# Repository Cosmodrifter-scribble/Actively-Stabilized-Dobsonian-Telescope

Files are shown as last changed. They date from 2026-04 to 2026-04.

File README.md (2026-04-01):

# Actively Stabilized Dobsonian Telescope

> An 8" f/5 GPS-controlled motorized Dobsonian telescope built completely from scratch — with closed-loop tracking, active stabilization, and Stellarium control. Built by Vinayak Soni, Indore, India.

---

## What is this?

This is a fully custom-built 8" Newtonian reflecting telescope on a motorized Dobsonian alt-azimuth mount. It started as a simple tracking telescope and evolved into something significantly more capable — a GPS-aligned, actively stabilized, astrophotography-ready instrument built for under ₹55,000 (~$580 USD).

A Celestron NexStar 8" costs over $2,000, lacks most of these features, and you'd never understand how it works. This one I built myself, and I understand every single part of it.

---

## Why I built this

I wanted to understand how modern telescopes actually work — not just use one. That meant building one from scratch, designing every subsystem, and solving every problem myself. Along the way the project grew from "make a basic tracker" into a full closed-loop stabilized GoTo system. The constraint of being in India — where quality optics are hard to find and Aliexpress is banned — pushed me to be creative and resourceful in ways I wouldn't have been otherwise.

---

## How to use it

1. Power on via the main switch — ESP32 boots, TMC2209 drivers initialize
2. Wait 30–60 seconds for NEO-M8N GPS to acquire satellite lock (blue LED turns on)
3. Select a target using the D-pad + OLED menu, or connect Stellarium on your phone over WiFi and click any object
4. Telescope slews to target automatically — both AZ and ALT axes move simultaneously
5. Sidereal tracking begins automatically — object stays centered as Earth rotates
6. Active stabilization via MPU9250 IMU corrects for vibration and wind at 200Hz
7. For astrophotography — attach DSLR via T-ring to the 2" Crayford focuser

---

## Features

| Feature | Details |
|---|---|
| GPS alignment | NEO-M8N — location + time on boot, no manual star alignment |
| Active stabilization | MPU9250 IMU at 200Hz — corrects vibration, wind shake, bumps |
| Closed-loop tracking | 1000PPR optical encoders on both axes — catches missed steps |
| Silent motors | TMC2209 at 32× microstepping — zero vibration |
| GoTo | Stellarium over WiFi (LX200 protocol) + built-in object catalogue |
| AZ accuracy | 360T ring gear — 0.003° per step |
| ALT accuracy | 120T GT2 belt — 0.009° per step |
| Dual core | ESP32-S3 — tracking on Core 0, UI/WiFi on Core 1 |

---

## Specifications

### Optics

| Parameter | Value |
|---|---|
| Primary mirror | GSO 8" f/5 parabolic, 203mm aperture, 1000mm focal length |
| Secondary mirror | GSO 50mm elliptical flat, 1/12 wave |
| Focuser | 2" Crayford (Marcos ATM design, modified for 228.6mm tube) |
| Limiting magnitude | ~14.5 |
| Magnification range | 31× to 250× |

### Tube

| Parameter | Value |
|---|---|
| Tube material | Aluminium |
| Tube OD | 228.6mm |
| Tube ID | 218.6mm |
| Total length | 1100mm |
| Spider position from top | 110mm |
| Secondary position from top | 154mm |
| Primary mirror position from top | 1000mm |
| Secondary offset | 2.26mm toward primary |

### Mount

| Parameter | Value |
|---|---|
| Mount type | Dobsonian alt-azimuth rocker box |
| Rocker box material | 12mm plywood (laser cut) |
| Side panels | 350×680mm |
| AZ bearing | 12" lazy susan + Teflon pads |
| ALT bearing | 25mm aluminium pipe + 2× 6205-2RS bearings |

### Drive System

| Axis | System | Ratio | Steps/rev | Accuracy |
|---|---|---|---|---|
| AZ | 360T Module 1 spur gear ring + 20T pinion | 18:1 | 115,200 | 0.003°/step |
| ALT | 120T GT2 belt + 20T pinion | 6:1 | 38,400 | 0.009°/step |

### Electronics

| Component | Spec |
|---|---|
| Controller | ESP32-S3-DevKitC-1-N8R8 |
| Motor drivers | 2× TMC2209 SilentStepStick, 32× microstep |
| Motors | 2× NEMA17, 4.2kg-cm, 1.8°/step |
| GPS | NEO-M8N with ceramic active antenna |
| IMU | MPU9250 9-axis (I2C 0x68) |
| Encoders | 2× 1000PPR AB-phase NPN open collector |
| Display | 1.3" 128×64 OLED (I2C 0x3C) |
| Power | 12V DC adapter → LM2596 buck → 5V → ESP32 |
| PCB | Custom 2-layer, 150×100mm |

---

## GPIO Assignment

| GPIO | Function |
|---|---|
| GPIO1 | AZ STEP |
| GPIO2 | AZ DIR |
| GPIO3 | ALT STEP |
| GPIO4 | ALT DIR |
| GPIO5 | TMC AZ UART (PDN) |
| GPIO6 | TMC ALT UART (PDN) |
| GPIO7 | TMC EN (both, active LOW) |
| GPIO8 | GPS TX |
| GPIO9 | GPS RX |
| GPIO10 | I2C SDA (IMU + Display) |
| GPIO11 | I2C SCL (IMU + Display) |
| GPIO12 | ALT Encoder A |
| GPIO13 | ALT Encoder B |
| GPIO14 | AZ Encoder A |
| GPIO15 | AZ Encoder B |
| GPIO19 | D-PAD CENTER |
| GPIO20 | D-PAD UP |
| GPIO21 | D-PAD DOWN |
| GPIO35 | D-PAD LEFT |
| GPIO36 | D-PAD RIGHT |
| GPIO37 | Toggle switch |
| GPIO38 | LED PWR (green) |
| GPIO39 | LED GPS (blue) |
| GPIO40 | LED TRACK (yellow) |
| GPIO41 | Battery ADC (12V → 3V via 27K+10K divider) |

---

## Repository Structure

```
Actively-Stabilized-Dobsonian-Telescope/
│
├── README.md
├── BOM.csv                          ← Full bill of materials with links
│
├── PCB/
│   ├── nigga.kicad_pro              ← KiCad project file
│   ├── nigga.kicad_sch              ← Schematic
│   ├── nigga.kicad_pcb              ← PCB layout
│   ├── gerbers/                     ← Gerber + drill files (zip for JLCPCB)
│   │   └── pcb_com.zip
│   ├── pcb_com_bom.csv              ← PCB BOM from KiCad
│   ├── pcb_com_positions.csv        ← Component placement file
│   ├── pcb_com_designators.csv      ← Designator reference
│   └── netlist.ipc                  ← IPC netlist
│
├── CAD/
│   ├── telescope.step               ← Full 3D assembly (STEP)
│   └── onshape_link.txt             ← Link to OnShape public document
│
├── firmware/
│   └── (in progress)
│
└── docs/
    └── (wiring diagrams, references)
```

---

## Build Progress

- [x] Mirror selection and optics sourcing
- [x] Mechanical design (OnShape)
- [x] Drive system design (AZ ring gear + ALT belt)
- [x] Schematic design (KiCad)
- [x] PCB layout and fabrication files
- [x] 3D printed parts design
- [ ] Firmware (in progress)
- [ ] Physical assembly
- [ ] Testing and calibration

---

## 3D Printed Parts

All parts printed in PETG. Source files in OnShape (link in `CAD/onshape_link.txt`).

| Part | Infill | Layer height |
|---|---|---|
| AZ ring gear segments (×6) | 60% | 0.15mm |
| ALT GT2 pulley 120T | 60% | 0.15mm |
| AZ pinion 20T | 80% | 0.15mm |
| ALT pinion 20T | 80% | 0.15mm |
| Mirror cell | 40% | 0.2mm |
| Spider hub | 40% | 0.2mm |
| Secondary mirror holder | 40% | 0.2mm |
| Motor mounts (×2) | 40% | 0.2mm |
| Tube rings (×2) | 20% | 0.2mm |
| Focuser mounting plate | 40% | 0.2mm |

---

## PCB

Custom 2-layer PCB designed in KiCad. All major modules (ESP32, GPS, IMU, motor drivers) are socketed for easy replacement and upgrades.

**Key design decisions:**
- TMC2209 modules in sockets — swappable without desoldering
- ESP32-S3 DevKit in pin headers — removable for programming
- LM2596 buck converter module for 12V→5V
- Separate power rails for motors (12V) and logic (3.3V)
- Ground planes on both F.Cu and B.Cu layers
- 1.5mm traces for power, 0.5mm for signals

Gerber files ready for JLCPCB or PCBWay in `PCB/gerbers/pcb_com.zip`.

---

## Acknowledgements

- **Marcos ATM** — 2" Crayford focuser design: https://marcosatm.com/2020/06/04/2in-crayford-focuser/
- **Thingiverse** — Focuser STL files: https://www.thingiverse.com/thing:4424419
- **Tejraj & Co.** — GSO optics supplier, India: +91 98339 74700

---

## Some Pic 

Screenshot (112)
Screenshot (111)
Screenshot (110)
Screenshot (109)
Screenshot (108)
Screenshot (107)
Screenshot (106)
Screenshot (105)
Screenshot (104)
Screenshot (103)
Screenshot (102)
Screenshot (101)
Screenshot (100)
Screenshot (99)

---

## Bill of Materials

| # | Component | Qty | Unit (₹) | Total (₹) | Source |
|---|---|---|---|---|---|
| 1 | [GSO 8" f/5 primary mirror](https://www.tejraj.com/product/gso-8-f5-parabolic-mirror) | 1 | ₹13,000 | ₹13,000 | Tejraj & Co. |
| 2 | [GSO 50mm secondary mirror](https://www.tejraj.com/product/50mm-secondary-mirror) | 1 | ₹5,500 | ₹5,500 | Tejraj & Co. |
| 3 | [32mm Plossl eyepiece](https://www.tejraj.com/product/32mm-plossl-eyepiece-125) | 1 | ₹3,350 | ₹3,350 | Tejraj & Co. |
| 4 | GSO 2" Crayford focuser + hardware | 1 | TBD | TBD | Local / Tejraj |
| 5 | [ESP32-S3-DevKitC-1-N8R8](https://www.electropi.in/espressif-esp32-s3-devkitc-1-n8r8-development-board) | 1 | ₹1,500 | ₹1,500 | Electropi.in |
| 6 | [NEMA17 4.2kg-cm stepper motor](https://robu.in/product/nema17-4-2-kgcm-stepper-motor/) | 2 | ₹700 | ₹1,400 | Robu.in |
| 7 | [TMC2209 stepper driver module](https://www.electropi.in/tmc2209-stepper-motor-driver-module) | 2 | ₹400 | ₹800 | Electropi.in |
| 8 | [1000PPR optical encoder (AB phase NPN)](https://www.amazon.in/Techtonics-2-Phase-Incremental-Optical-Quadrature/dp/B0DCK8HMHN) | 2 | ₹1,850 | ₹3,700 | Amazon.in |
| 9 | [LM2596 buck converter module](https://robu.in/product/lm2596s-dc-dc-buck-converter-power-supply/) | 1 | ₹45 | ₹45 | Robu.in |
| 10 | [MPU9250 9-axis IMU](https://www.electropi.in/mpu9250-9-axis-gyro-accelerometer-module) | 1 | ₹350 | ₹350 | Electropi.in |
| 11 | [NEO-M8N GPS module](https://www.electropi.in/neo-m8n-gps-module-with-ceramic-active-antenna) | 1 | ₹900 | ₹900 | Electropi.in |
| 12 | [1.3" 128×64 OLED display](https://www.electropi.in/1.3-inch-128x64-oled-display-screen-module-with-spi-serial-interface-v2) | 1 | ₹350 | ₹350 | Electropi.in |
| 13 | Custom PCB (2-layer, 150×100mm) | 1 | ₹2,500 | ₹2,500 | JLCPCB / PCBWay |
| 14 | Resistor 4.7K (encoder pullup) | 4 | TBD | TBD | Local Palasia |
| 15 | Resistor 330Ω (LED) | 3 | TBD | TBD | Local Palasia |
| 16 | Resistor 10K (EN pullup + I2C) | 3 | TBD | TBD | Local Palasia |
| 17 | Resistor 27K (ADC divider) | 1 | TBD | TBD | Local Palasia |
| 18 | Capacitor 100µF electrolytic | 2 | TBD | TBD | Local Palasia |
| 19 | LED green + blue + yellow 5mm | 3 | TBD | TBD | Local Palasia |
| 20 | JST 4-pin connector (motor ×2, display ×1, GPS ×1) | 4 | TBD | TBD | Local Palasia |
| 21 | JST 5-pin connector (encoder) | 2 | TBD | TBD | Local Palasia |
| 22 | JST 10-pin connector (IMU) | 1 | TBD | TBD | Local Palasia |
| 23 | Toggle switch SPDT | 2 | TBD | TBD | Local Palasia |
| 24 | 5-way tactile switch breakout 7-pin | 1 | TBD | TBD | Robu.in / Amazon |
| 25 | Pin headers male/female | — | TBD | TBD | Local Palasia |
| 26 | 12V DC adapter 3A | 1 | TBD | TBD | Local / Amazon |
| 27 | Wiring (various) | — | TBD | TBD | Local Palasia |
| 28 | Aluminium tube (telescope body) | 1 | TBD | TBD | Local Indore |
| 29 | 12mm plywood (rocker box + ground board) | 1 | ₹1,000 | ₹1,000 | Local Indore |
| 30 | Plywood laser cutting | 1 | ₹1,000 | ₹1,000 | Local Indore |
| 31 | [12" lazy susan bearing](https://www.amazon.in/BOSCO-Swivel-Turntable-Rotating-Furniture/dp/B0GSGZFKGD) | 1 | ₹650 | ₹650 | Amazon.in |
| 32 | Spider vane steel strip 0.8×15×109mm | 4 | TBD | TBD | Local Palasia |
| 33 | 25mm aluminium pipe (ALT axis) | 1 | TBD | TBD | Local Indore |
| 34 | 6205-2RS bearing 25mm bore | 2 | TBD | TBD | Local Indore |
| 35 | GT2 belt 6mm | 1 | TBD | TBD | Robu.in |
| 36 | Teflon pads | 3 | TBD | TBD | Local hardware |
| 37 | M3 screws (secondary ×3, tube ×4, pulleys ×4) | 11 | TBD | TBD | Local Palasia |
| 38 | M4 screws (big pulley ×2) | 2 | TBD | TBD | Local Palasia |
| 39 | M5 screws (primary cell ×6) | 6 | TBD | TBD | Local Palasia |
| 40 | M6 screws (tube rings ×6) | 6 | TBD | TBD | Local Palasia |
| 41 | Nylon M2 screws (mirror holder) | 6 | TBD | TBD | Local Palasia |
| 42 | All PETG 3D printed parts | 1 | ₹10,000 | ₹10,000 | 3Ding.in / Aprintpro |
| 43 | RTV silicone (mirror mounting) | 1 | TBD | TBD | Local hardware |
| — | **Total (known)** | | | **₹46,045** | **≈ $490 USD** |

---

*Built in Indore, Madhya Pradesh, India.*

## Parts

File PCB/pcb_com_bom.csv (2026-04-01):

Designator | Footprint | Quantity | Value | LCSC Part #
C1, C2 | CP_Radial_D6.3mm_P2.50mm | 2 | 100µF
D1, D2, D3 | LED_D5.0mm | 3 | LED
J1 | BarrelJack_CUI_PJ-102AH_Horizontal | 1 | JACK
J10 | PinHeader_1x04_P2.54mm_Vertical | 1 | M_ALT
J11 | PinHeader_1x04_P2.54mm_Vertical | 1 | M_AZ
J2 | PinHeader_1x03_P2.54mm_Vertical | 1 | MAIN SWITCH
J3 | PinHeader_1x05_P2.54mm_Vertical | 1 | EN_ALT
J4 | PinHeader_1x05_P2.54mm_Vertical | 1 | EN_AZ
J5 | PinHeader_1x04_P2.54mm_Vertical | 1 | GPS
J6 | PinHeader_1x10_P2.54mm_Vertical | 1 | IMU
J7 | PinHeader_1x04_P2.54mm_Vertical | 1 | DISPLAY
J8 | PinHeader_1x03_P2.54mm_Vertical | 1 | SWITCH
J9 | PinHeader_1x07_P2.54mm_Vertical | 1 | D-PAD
PS1 | CONV_MC00100 | 1 | LM2596
R1, R12 | R_Axial_DIN0207_L6.3mm_D2.5mm_P10.16mm_Horizontal | 2 | 10K
R10, R2, R3, R4, R5, R9 | R_Axial_DIN0207_L6.3mm_D2.5mm_P10.16mm_Horizontal | 6 | 4.7K
R11 | R_Axial_DIN0207_L6.3mm_D2.5mm_P10.16mm_Horizontal | 1 | 27K
R6, R7, R8 | R_Axial_DIN0207_L6.3mm_D2.5mm_P10.16mm_Horizontal | 3 | 330
U1 | MODULE_TMC2209_SILENTSTEPSTICK | 1 | ALT
U2 | MODULE_TMC2209_SILENTSTEPSTICK | 1 | AZ
U3 | ESP32-S3-DEVKITC-1-N8R8 | 1 | ESP32-S3-DEVKITC-1-N8R8

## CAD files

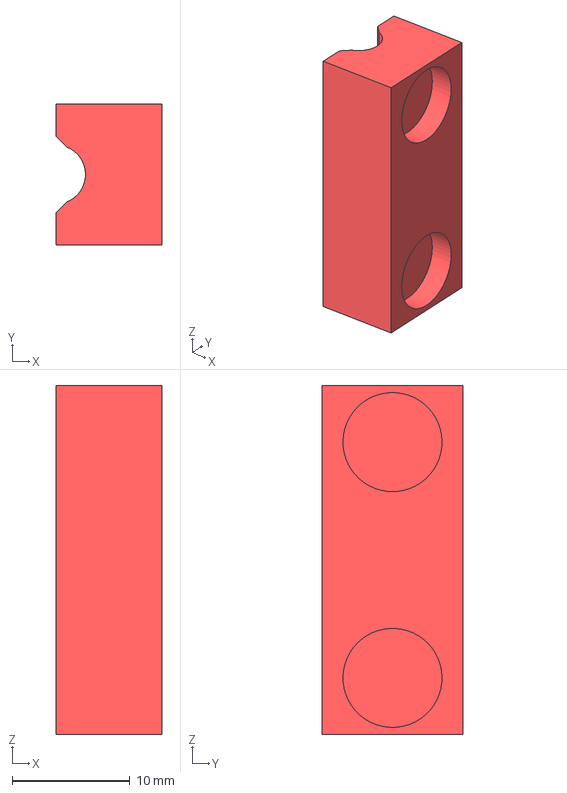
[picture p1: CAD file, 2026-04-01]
3D MODEL FILES/CRAY_pusher block.step
9.00 x 12.0 x 29.6 mm

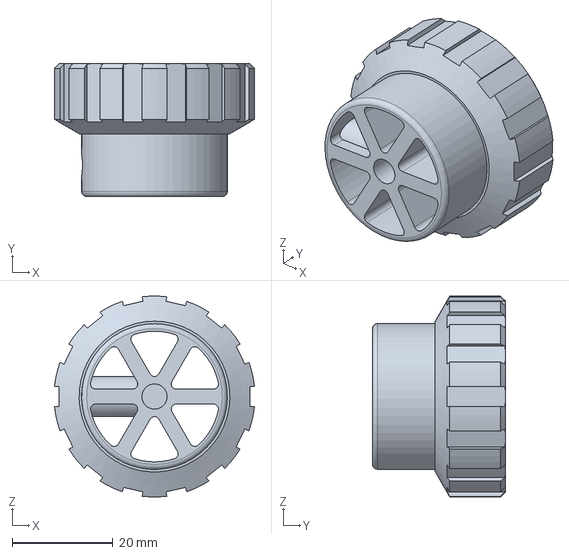
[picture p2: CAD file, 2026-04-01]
3D MODEL FILES/CRAY_knob 2.step
39.8 x 26.5 x 40.0 mm

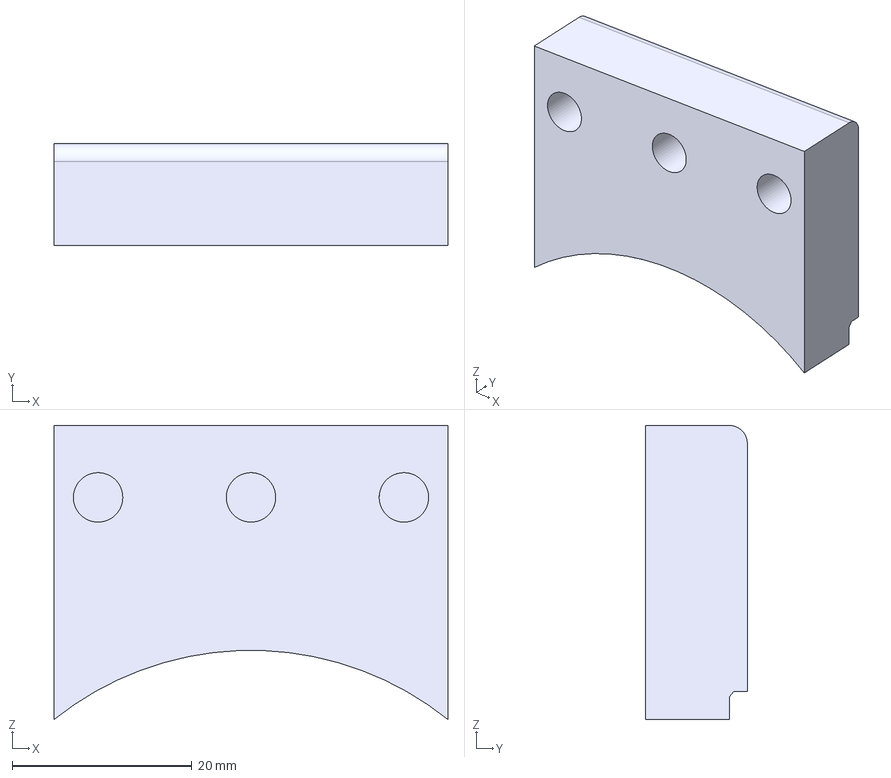
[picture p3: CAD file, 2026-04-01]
3D MODEL FILES/CRAY_baseplate tension cover.step
43.8 x 11.3 x 32.7 mm

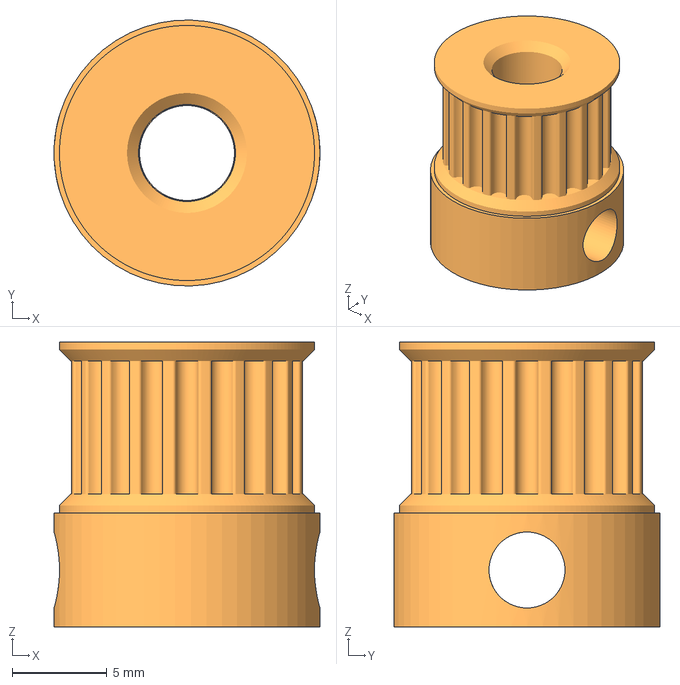
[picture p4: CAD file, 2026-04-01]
3D MODEL FILES/ALT pulley.step
14.0 x 14.0 x 15.0 mm

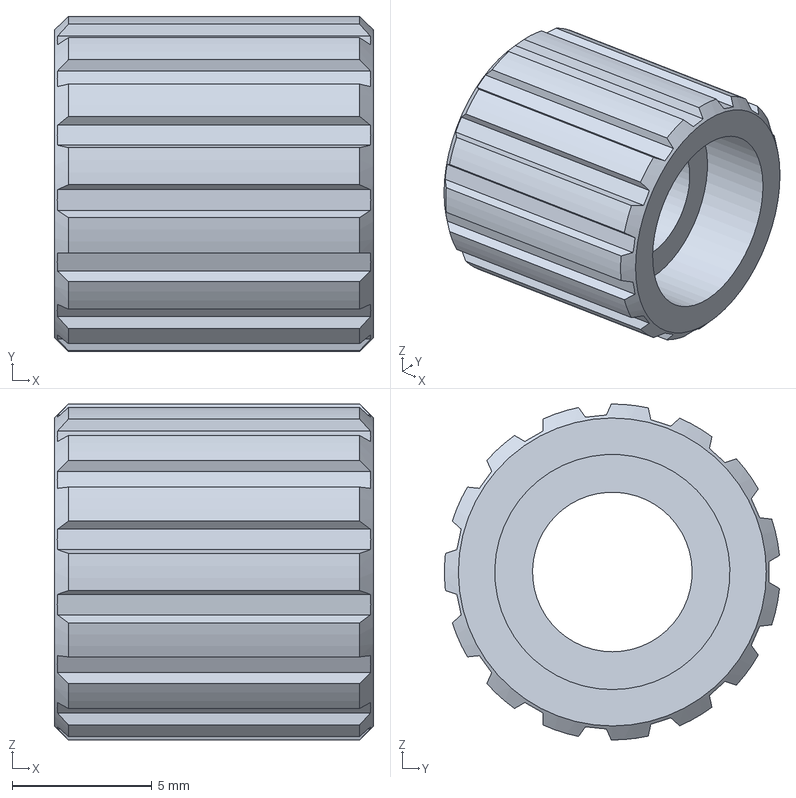
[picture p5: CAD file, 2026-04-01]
3D MODEL FILES/CRAY_lock knob.step
11.4 x 12.0 x 12.0 mm

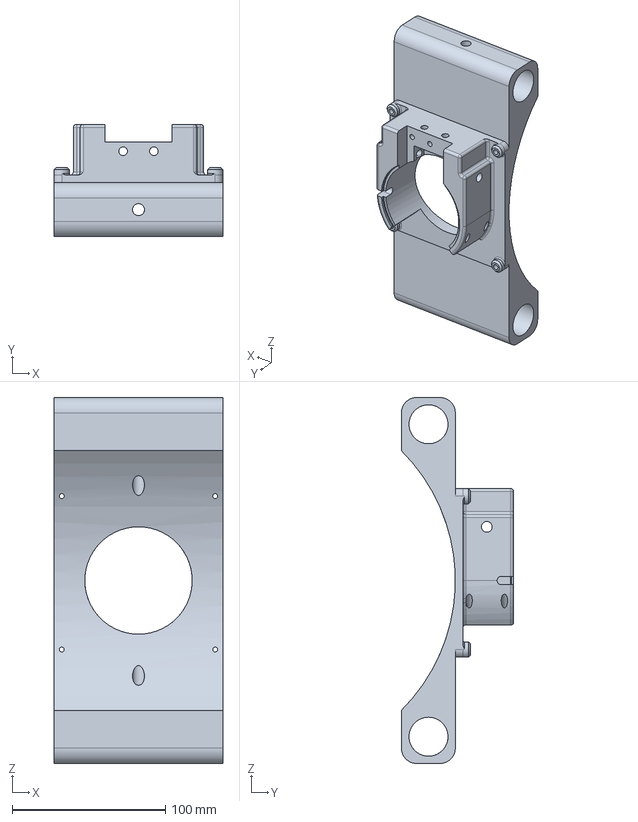
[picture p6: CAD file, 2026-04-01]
3D MODEL FILES/CRAY_base plate[modified].step
110.0 x 73.2 x 238.6 mm

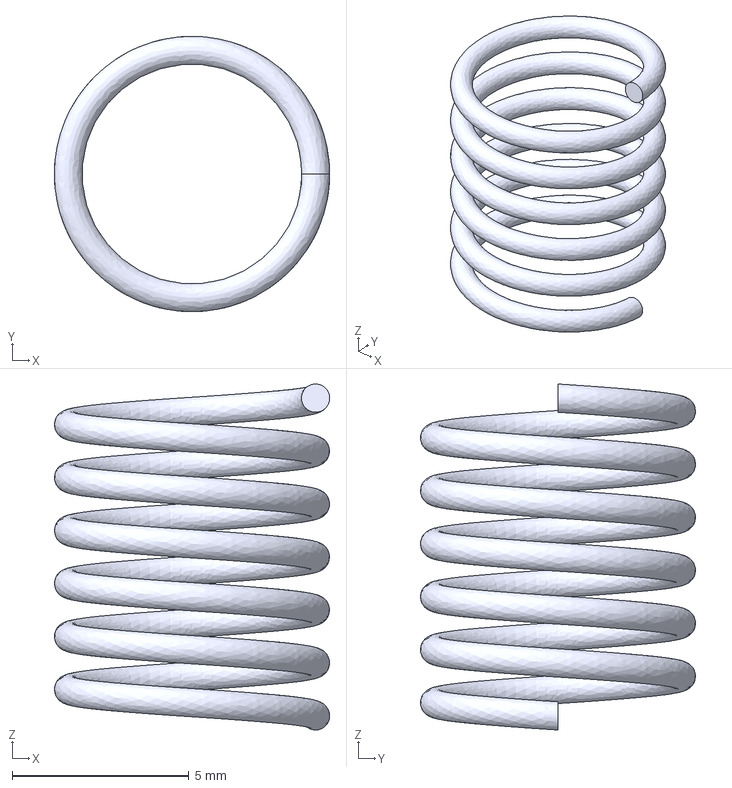
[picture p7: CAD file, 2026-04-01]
3D MODEL FILES/CRAY_pinion tension spring.step
7.80 x 7.80 x 9.80 mm

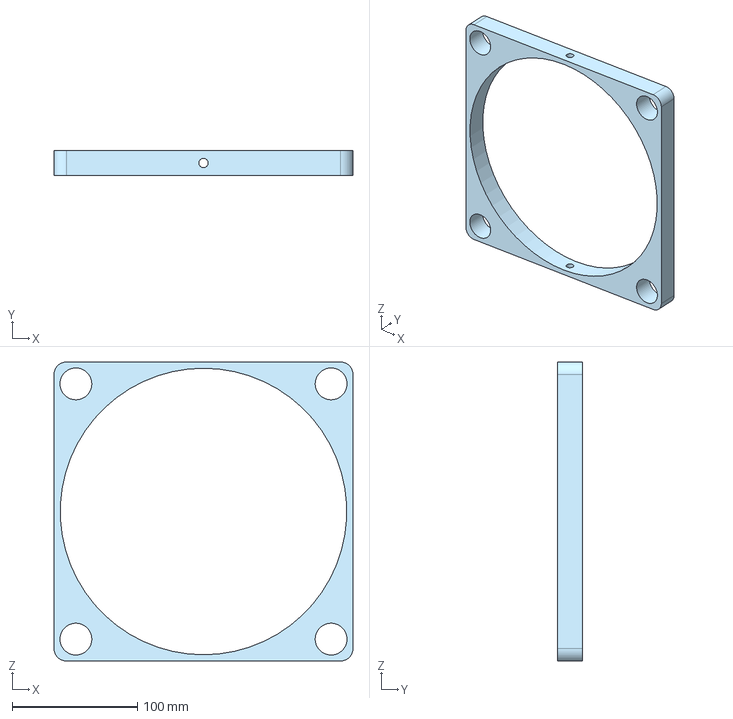
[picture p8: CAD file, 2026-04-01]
3D MODEL FILES/TUBE v2 - tube ring.step
238.6 x 20.0 x 238.6 mm

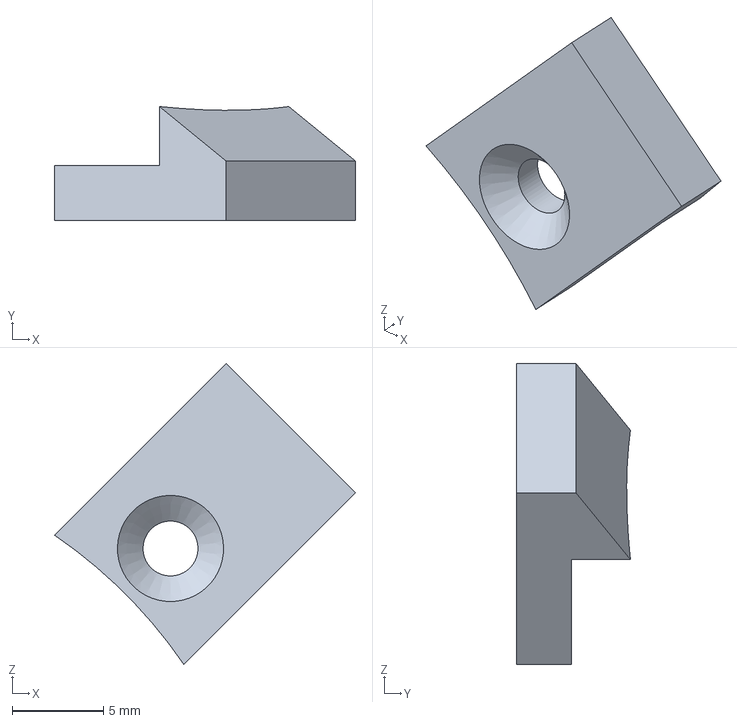
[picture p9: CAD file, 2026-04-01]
3D MODEL FILES/CRAY_stop tab.step
16.5 x 6.23 x 16.5 mm

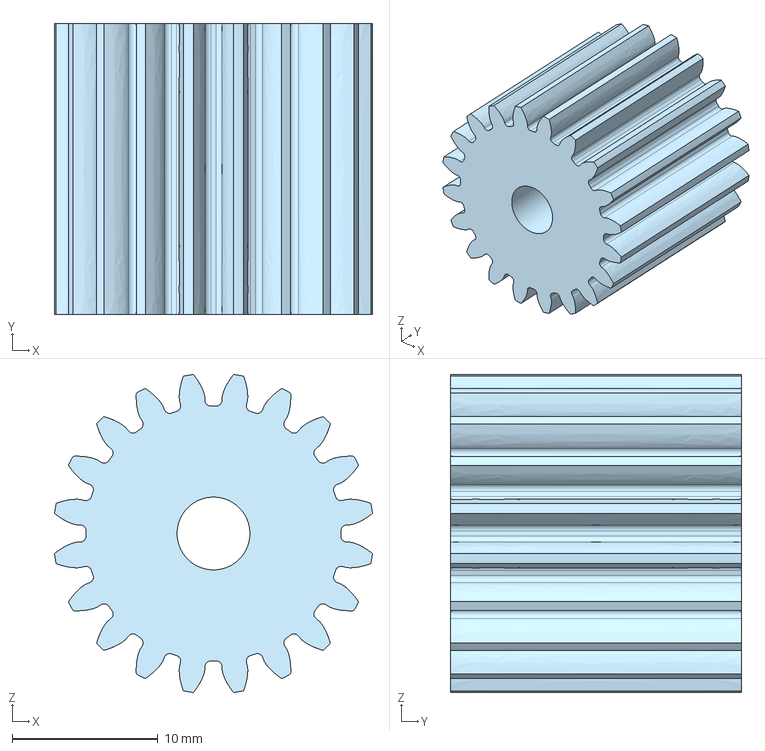
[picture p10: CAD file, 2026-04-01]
3D MODEL FILES/AZ gear.step
21.8 x 20.0 x 21.8 mm

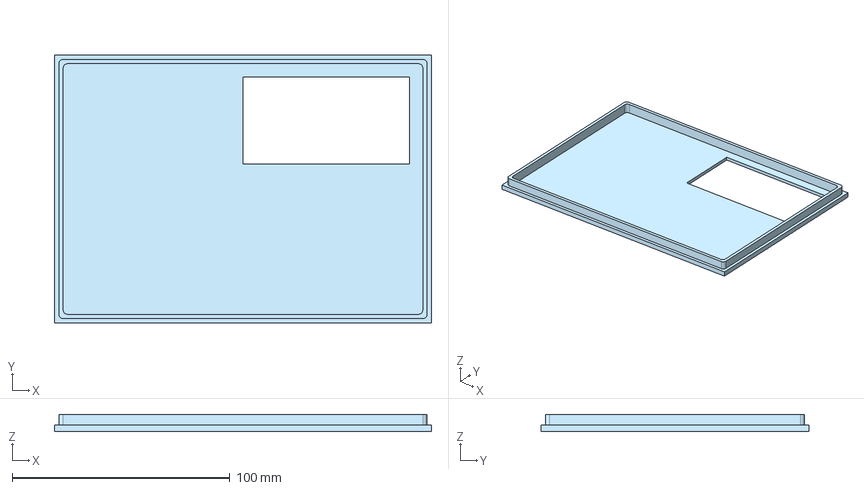
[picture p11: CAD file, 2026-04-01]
3D MODEL FILES/box lid.step
173.0 x 123.0 x 8.00 mm

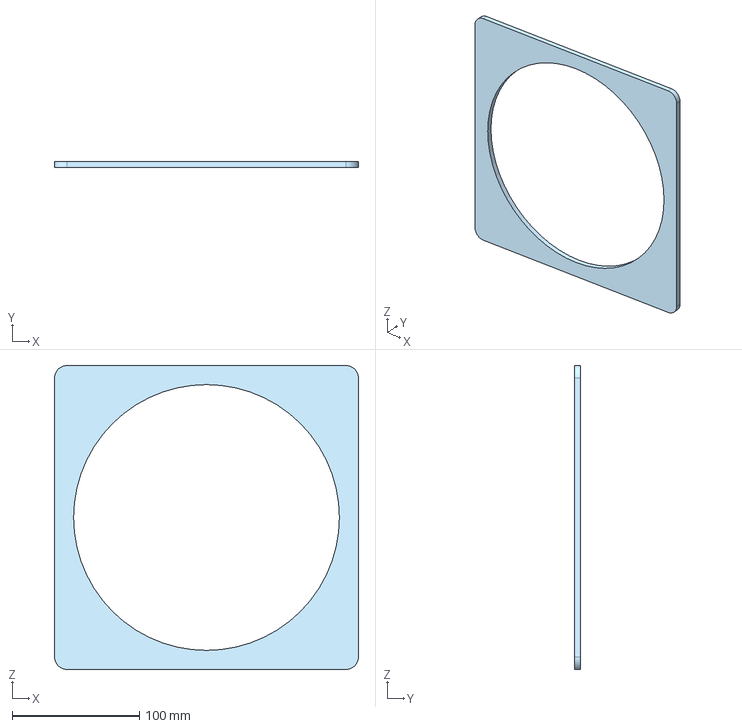
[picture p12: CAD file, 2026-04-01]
3D MODEL FILES/tube cover - tube front-back cover.step
238.6 x 5.00 x 238.6 mm

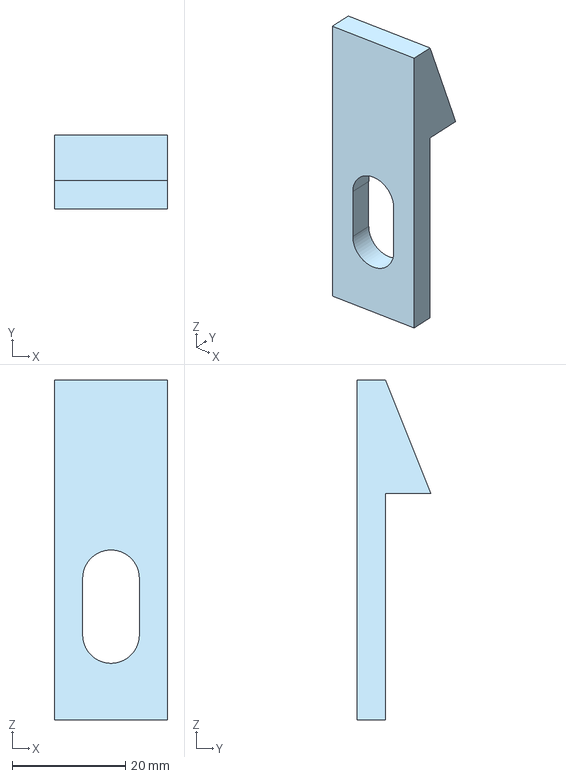
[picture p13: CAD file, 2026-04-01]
3D MODEL FILES/side bar.step
20.0 x 13.0 x 60.0 mm

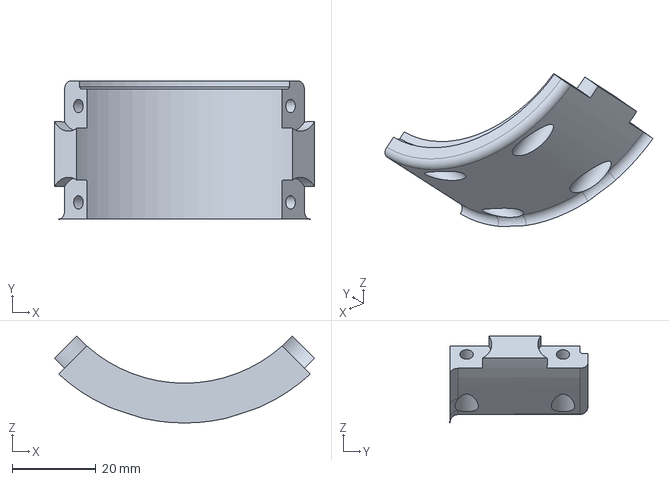
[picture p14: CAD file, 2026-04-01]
3D MODEL FILES/CRAY_rear brace.step
62.1 x 33.0 x 20.8 mm

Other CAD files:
3D MODEL FILES/ALT big pulley.step
3D MODEL FILES/primary mirror cell.step
3D MODEL FILES/CRAY_spring push pin.step
3D MODEL FILES/AZ tooth.step
3D MODEL FILES/CRAY_2in drawtube.step
3D MODEL FILES/TUBE v2 - tube middle ring.step
3D MODEL FILES/box.step
3D MODEL FILES/spider vane.step

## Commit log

2026-03-31 Create BOM
2026-03-31 Create PCB
2026-04-01 Update BOM
